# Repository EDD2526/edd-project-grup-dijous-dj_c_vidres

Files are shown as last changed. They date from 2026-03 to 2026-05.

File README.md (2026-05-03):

View this project on [CADLAB.io](https://cadlab.io/project/30197).

# Projecte DJ_C_Vidres (Portes)

> **Autors: Gurpinder Singh Kaur, Adria Pelegri Sabate**  
> **Versió: 5**

---

## Objectiu

PCB per al control d’un sistema de porta i alçavidres d’un vehicle. La placa permet controlar el moviment del vidre i l’actuació de la porta mitjançant botons, gestionar motors amb drivers pont H, detectar finals de carrera i situacions de sobrecorrent, i comunicar-se amb altres sistemes del vehicle mitjançant CAN. També inclou mecanismes de protecció, regulació d’alimentació, programació/debug mitjançant ICSP i test points per facilitar la depuració.

---

## Diagrama de blocs

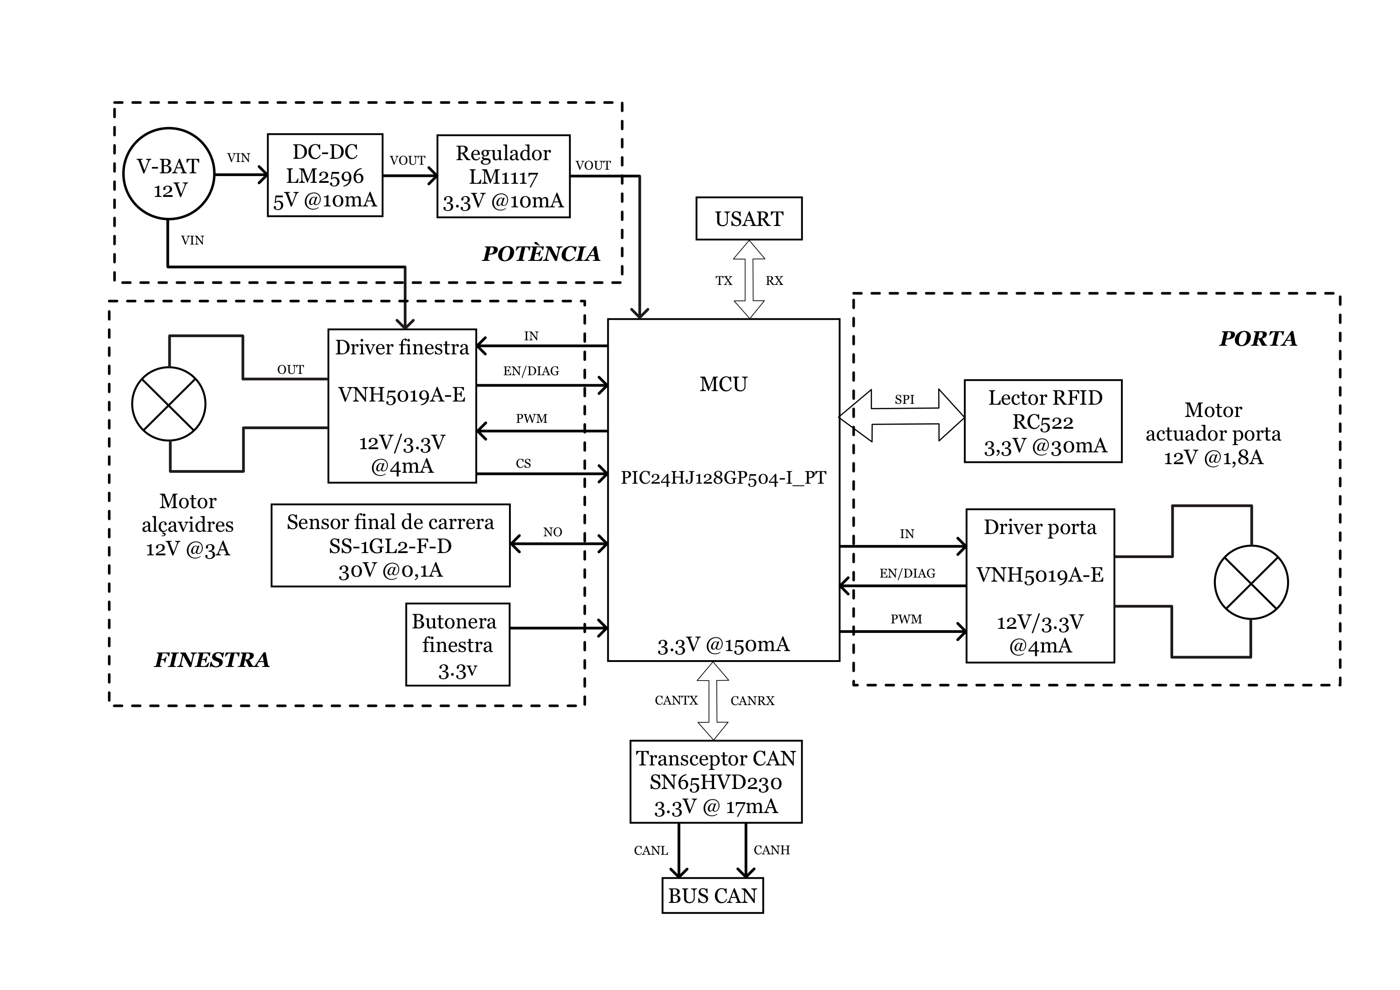
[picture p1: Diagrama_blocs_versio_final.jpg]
Diagrama de blocs


---

## Descripció funcional dels blocs

### Alimentació

La placa s’alimenta a partir d’una entrada de 12 V del vehicle. Aquesta entrada està protegida mitjançant fusible, díode de protecció i TVS. A partir d’aquesta tensió es genera una línia de 5 V mitjançant un convertidor DC-DC LM2596S-5.0. Posteriorment, es genera una línia de 3.3 V mitjançant un regulador LM1117-3.3 per alimentar la lògica digital, el microcontrolador, el transceptor CAN i els perifèrics de baixa tensió.

### Microcontrolador

El sistema està controlat per un microcontrolador **PIC24HJ128GP504-I/PT** alimentat a 3.3 V. Aquest dispositiu gestiona les entrades de botons i sensors, genera les ordres de control dels drivers de motor, llegeix el senyal analògic de corrent, comunica amb el lector RFID i permet la comunicació amb altres sistemes mitjançant CAN.

La placa inclou connector de programació/debug ICSP amb les línies MCLR, PGEC i PGED.

### Drivers de motor

S’utilitzen dos drivers **VNH5019A-E** en configuració de pont H:

- Un driver per al motor  de l’alçavidres;
- Un driver per al motor actuador de la porta.

Cada driver permet controlar el motor en ambdós sentits mitjançant senyals digitals INA, INB i PWM.

### Mesura de corrent i antiatrapament

La mesura de corrent es realitza mitjançant la sortida de current sense del driver VNH5019A-E. Aquest senyal s’envia a una entrada ADC del microcontrolador per detectar situacions de sobrecorrent. Aquesta informació permet implementar una funció  tipus antiatrapament en el motor de l’alçavidres.

### Inputs d’usuari i sensors

La placa incorpora entrades per a:

- Botons de pujada i baixada de l’alçavidres
- Control de bloqueig/desbloqueig de porta
- Sensor de final de carrera

Les entrades digitals es connecten al microcontrolador mitjançant resistències de pull-up/pull-down segons la funcionalitat requerida.

### RFID

El sistema inclou connexió per a un lector RFID RC522. Aquest mòdul permet identificar l’usuari o autoritzar accions del sistema. La comunicació amb el microcontrolador es realitza mitjançant SPI.

### Comunicació CAN

La comunicació amb altres sistemes del vehicle es realitza mitjançant un transceptor **SN65HVD230**. El bus CAN disposa de les línies CANH i CANL.

---

## Requisits / Especificacions

### Alimentació

- Entrada principal: 12 V
- Sortida intermèdia: 5 V
- Alimentació lògica: 3.3 V
- Protecció d’entrada mitjançant fusible, díode i TVS

### Microcontrolador

- Model: PIC24HJ128GP504-I/PT
- Encapsulat: TQFP-44
- Alimentació: 3.3 V
- Programació/debug: ICSP
- Perifèrics utilitzats:
  - PWM per al control dels motors
  - ADC per a la lectura de corrent
  - SPI per al lector RFID
  - CAN per a la comunicació amb el vehicle
  - GPIO per a botons, sensors i diagnòstic

### Motors

- Motor alçavidres:
  - Alimentació: 12 V
  - Corrent màxim estimat: fins a 3 A

- Motor actuador de porta:
  - Alimentació: 12 V
  - Control bidireccional mitjançant pont H
  - Control PWM

### Funcionalitats principals

- Control bidireccional dels motors
- Control de velocitat mitjançant PWM
- Lectura de botons d’usuari
- Lectura de final de carrera
- Detecció de sobrecorrent
- Diagnòstic dels drivers de motor
- Comunicació CAN
- Connexió RFID
- Programació i debug mitjançant ICSP
- Test point per depuració

---

## Components principals

| # | Component | Valor | Quantitat | Footprint | Preu x1 (€) |
|---|---|---|---|---|---|
| 1 | Capacitor | 100nF | 12 | Capacitor_SMD:C_0805_2012Metric | 0,09 |
| 2 | Capacitor | 10uF | 6 | Capacitor_SMD:C_0805_2012Metric | 0,79 |
| 3 | Capacitor | 220uF | 1 | Capacitor_SMD:CP_Elec_8x10 | 0,46 |
| 4 | Capacitor | 22pF | 2 | Capacitor_SMD:C_0805_2012Metric | 0,67 |
| 5 | Capacitor | 100uF | 1 | Capacitor_SMD:CP_Elec_8x10 | 0,69 |
| 6 | Diode Schottky | - | 2 | Diode_SMD:D_SMB_Modified | 0,22 |
| 7 | Diode TVS | - | 1 | Diode_SMD:D_SMB_Modified | 0,66 |
| 8 | Fuse | - | 1 | Fuse:Fuse_1812_4532Metric | 0,45 |
| 9 | Connector | - | 2 | Connector_Dsub:DSUB-9_Pins_Horizontal_P2.77x2.84mm_EdgePinOffset4.9 | 3,89 |
| 10 | Connector | - | 1 | Connector_PinSocket_1.00mm:PinSocket_1x08_P1.00mm_Vertical | 0,80 |
| 11 | Connector | - | 1 | Connector_PinHeader_2.54mm:PinHeader_1x05_P2.54mm_Vertical | 0,24 |
| 12 | Connector | - | 4 | TerminalBlock:TerminalBlock_MaiXu_MX126-5.0-02P_1x02_P5.00mm | 0,09 |
| 13 | Inductor | 33uH | 1 | Inductor_SMD:L_10.4x10.4_H4.8 | 1,38 |
| 14 | Resistor | 120Ω | 1 | Resistor_SMD:R_0805_2012Metric | 1,08 |
| 15 | Resistor | 10kΩ | 10 | Resistor_SMD:R_0805_2012Metric | 1,08 |
| 16 | Resistor | 1kΩ | 1 | Resistor_SMD:R_0805_2012Metric | 1,08 |
| 17 | Switch | - | 1 | Button_Switch_SMD:SW_DPDT_CK_JS202011JCQN | 0,86 |
| 18 | Switch | - | 1 | Button_Switch_THT:SW_CK_JS202011CQN_DPDT_Straight | 0,74 |
| 19 | Switch | - | 1 | Button_Switch_SMD:SW_SPST_TL3342 | 0,50 |
| 20 | Micro | - | 1 | PIC24HJ128GP504-I_PT:QFP80P1200X1200X120-44N | 7,23 |
| 21 | Transceiver | - | 1 | PACKAGE_SO:SOIC-8_3.9x4.9mm_P1.27mm | 1,87 |
| 22 | Motor Drivers | - | 2 | Package_SO:ST_MultiPowerSO-30 | 7,93 |
| 23 | DC-DC | - | 1 | Package_TO_SOT_SMD:TO-263-5_TabPin3 | 5,99 |
| 24 | DC-DC | - | 1 | Package_TO_SOT_SMD:TO-252-3_TabPin2 | 1,12 |
| 25 | Crystal | 8MHz | 1 | Crystal:Crystal_SMD_3225-4Pin_3.2x2.5mm | 0,53 |

## Disseny PCB

La PCB s’ha dissenyat a **dues capes**. S’ha intentat separar funcionalment la zona de potència i la zona lògica per reduir interferències i facilitar el routing.

### Criteris principals de disseny

- Zona de potència situada principalment a l’esquerra de la PCB.
- Microcontrolador situat a la zona central.
- Comunicacions CAN i connectors principals situats a la dreta.
- Inputs i botons situats a la zona inferior/superior.
- Pla de VBAT_PROT per alimentar els drivers de motor.
- Pla de +3.3V per alimentar la part digital.
- Separació entre GND i GNDPWR
- Pistes de potència més amples que les pistes de senyal.
- Test points  per a alimentació, debug, CAN, PWM, diagnòstic i corrent.

### Bus CAN

El transceptor CAN s’ha col·locat pròxim al connector corresponent. Les línies `CANH` i `CANL` s’han mantingut curtes i amb una disposició simètrica.

---

## Test points

S’han afegit test points per facilitar la posada en marxa i la depuració de la placa. Els punts principals són:

- TP_VBAT: alimentació protegida de 12 V
- TP_5V: sortida del convertidor DC-DC
- TP_3V3: alimentació lògica
- TP_GND: massa lògica
- TP_GNDPWR: massa de potència
- TP_MCLR: reset/programació
- TP_PGEC: línia de clock ICSP
- TP_PGED: línia de dades ICSP
- TP_CANH: línia CANH
- TP_CANL: línia CANL
- TP_CURRENT: lectura de corrent
- TP_PWM: control PWM
- TP_WDIAG: diagnòstic del driver de finestra
- TP_DDIAG: diagnòstic del driver de porta

Aquests punts permeten verificar alimentació, comunicació, programació, control dels motors i diagnòstic sense modificar la placa.

---

## Software

### Eines utilitzades

- KiCad 9.0
- LTspice per a simulacions

### Configuració prevista del microcontrolador

- PWM per al control dels drivers de motor
- ADC per a lectura del senyal de corrent
- SPI per al lector RFID
- CAN per a comunicació amb el vehicle
- GPIO per a botons, sensors, finals de carrera i diagnòstic
- ICSP per a programació i debug

### Funcionalitats previstes

#### Control de motors

- Control de pujada i baixada del vidre
- Control d’actuació de la porta
- Control de velocitat mitjançant PWM
- Control de sentit mitjançant INA i INB

#### Seguretat

- Detecció de sobrecorrent
- Funció antiatrapament
- Lectura de final de carrera
- Diagnòstic dels drivers de motor

#### Comunicació

- Comunicació CAN amb altres sistemes del vehicle
- Comunicació SPI amb el lector RFID

#### Debug

- Programació mitjançant ICSP
- Test points per a mesures elèctriques

---

## Verificació

Abans de la fabricació/entrega s’han revisat els punts següents:

- ERC del circuit esquemàtic:
  - 0 errors
  - 6 avisos 
- DRC de la PCB:
  - 0 errors
  - 0 avisos
- Separació entre zona de potència i zona lògica.
- Bus CAN curt i simètric.
- Serigrafia completa i llegible.
- Test points accessibles.

---

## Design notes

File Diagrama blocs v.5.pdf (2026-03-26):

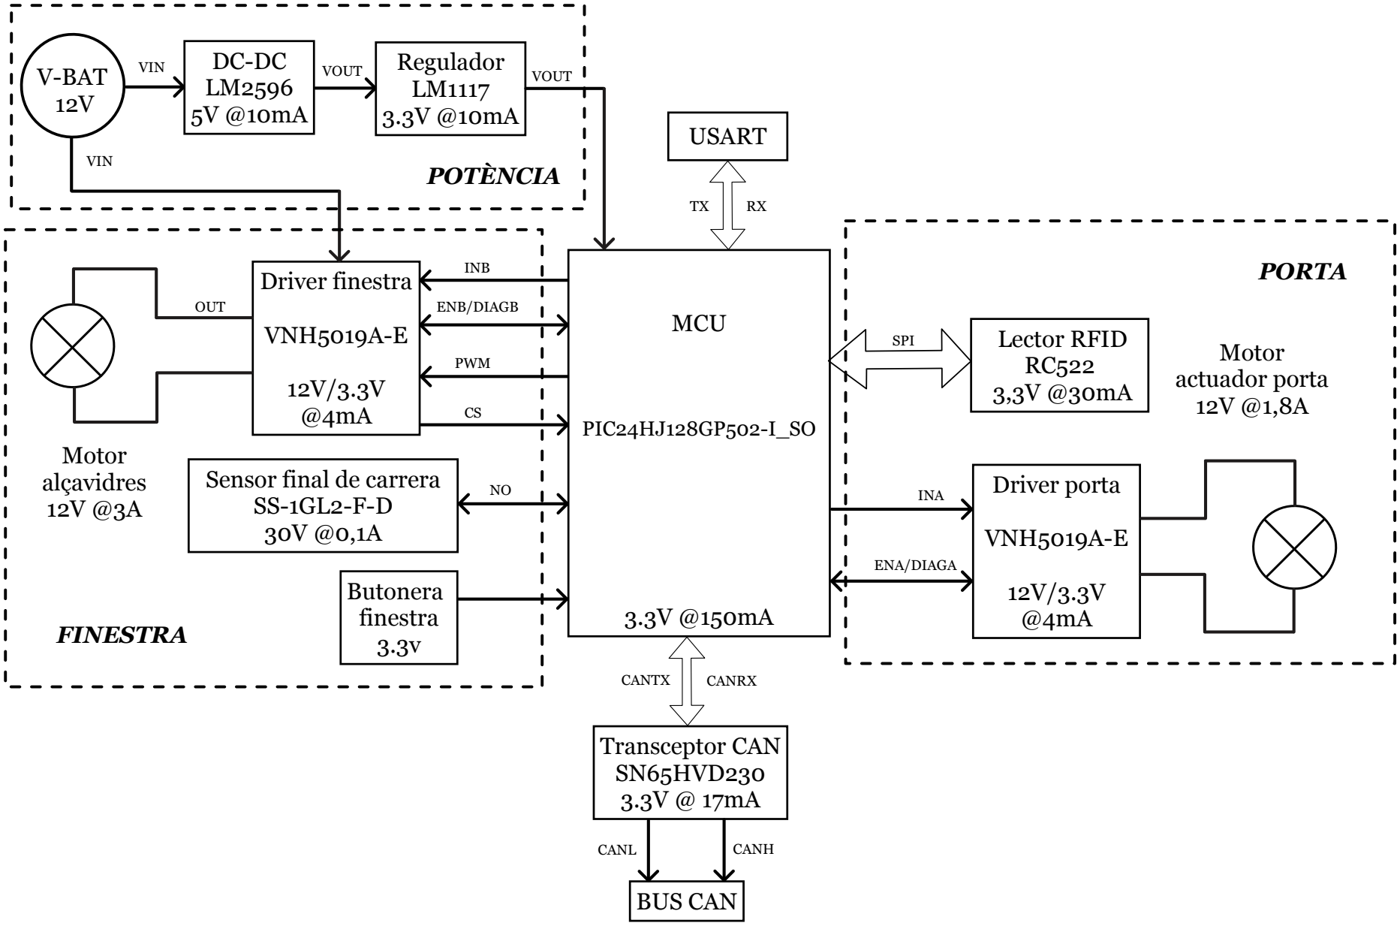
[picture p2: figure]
Regulador LM1117 3.3V @10mA; MCU; PIC24HJ128GP502-I_SO; USART; Lector RFID RC522 3,3V @30mA; Transceptor CAN SN65HVD230 3.3V @ 17mA; CANL; CANH; CANTX; CANRX; Driver finestra; VNH5019A-E; INB; PWM; Motor alçavidres 12V @3A; OUT; Motor actuador porta 12V @1,8A; Butonera finestra 3.3v; Sensor final de carrera SS-1GL2-F-D 30V @0,1A; VIN; VOUT; BUS CAN; V-BAT 12V; FINESTRA; ENB/DIAGB; Driver porta; INA; ENA/DIAGA; PORTA; POTÈNCIA; SPI

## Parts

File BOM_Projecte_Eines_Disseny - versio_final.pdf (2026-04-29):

Component | Descripció | Ref. Fabricant | Package | Datasheet | Proveïdor | Preu | Unitats
PIC24HJ128GP504-I_PT | Microcontrolador | PIC24HJ128GP504-I/PT-ND | | Datasheet (https://ww1.microchip.com/downloads/en/DeviceDoc/70293G.pdf) | DigiKey (https://www.digikey.es/es/products/detail/microchip-technology/PIC24HJ128GP504-I-PT/1635638) | 7,23 € | 1x
LM1117DT-3.3 | Regulador 3.3V | 926-LM1117DTX3.3NOPB | | Datasheet (https://www.ti.com/lit/ds/symlink/lm1117.pdf?ts=1773808432939) | Mouser (https://www.mouser.es/ProductDetail/Texas-Instruments/LM1117DTX-3.3-NOPB?qs=X1J7HmVL2ZFMDtR97FJi7A%3D%3D) | 1,12 € | 1x
LM2596S-5.0 | Regulador 5V | 926-LM2596S-5.0/NOPB | | Datasheet (https://www.ti.com/lit/ds/symlink/lm2596.pdf?ts=1777428369397) | Mouser (https://www.mouser.es/ProductDetail/Texas-Instruments/LM2596S-5.0-NOPB?qs=X1J7HmVL2ZHVjCOmW%252BYINA%3D%3D) | 5,99 € | 1x
VNH5019A-E | H-Bridge (Drivers) | 511-VNH5019A-E | | Datasheet (https://www.st.com/resource/en/datasheet/vnh5019a-e.pdf) | Mouser (https://www.mouser.es/ProductDetail/STMicroelectronics/VNH5019A-E?qs=vV0pr1uq7fB8hoIFkGw2pA%3D%3D) | 7,93 € | 1x
ACI 83094 | Motor alçavidres | | | | AutoZone (https://www.autozone.com/p/aci-window-motor-83094/972601) | 86,99 € | 1x
CINCHING LATCH MOTOR | Motor actuador porta | | | | Johnson Electric (https://shop.johnsonelectric.com/products/cinching-latch-motors) | 30,00 € | 1x
RC522 | Lector RFID | Modulo RFID RC522 | | | ElectroComponentes (https://www.electrocomponentes.es/modulos/825-modulo-rfid-rc522-1356mhz-33v-con-tarjeta-y-llavero.html) | 2,20 € | 1x
SN65HVD230 | Transceptor CAN | 595-SN65HVD230DR | | Datasheet (https://www.ti.com/lit/ds/symlink/sn65hvd232.pdf?ts=1773819356784) | Mouser (https://www.mouser.es/ProductDetail/Texas-Instruments/SN65HVD230DR?qs=QViXGNcIEAtifeQR3pYVUQ%3D%3D) | 1,87 € | 1x
SS-5GLD | Sensor final de carrera | 653-SS-5GLD | | Datasheet (https://www.mouser.es/datasheet/3/39/1/B032-E1.pdf) | Mouser (https://www.mouser.es/ProductDetail/Omron-Electronics/SS-5GLD?qs=0w99tykdtPIPkyQBY6Ojgw%3D%3D) | 2,38 € | 1x

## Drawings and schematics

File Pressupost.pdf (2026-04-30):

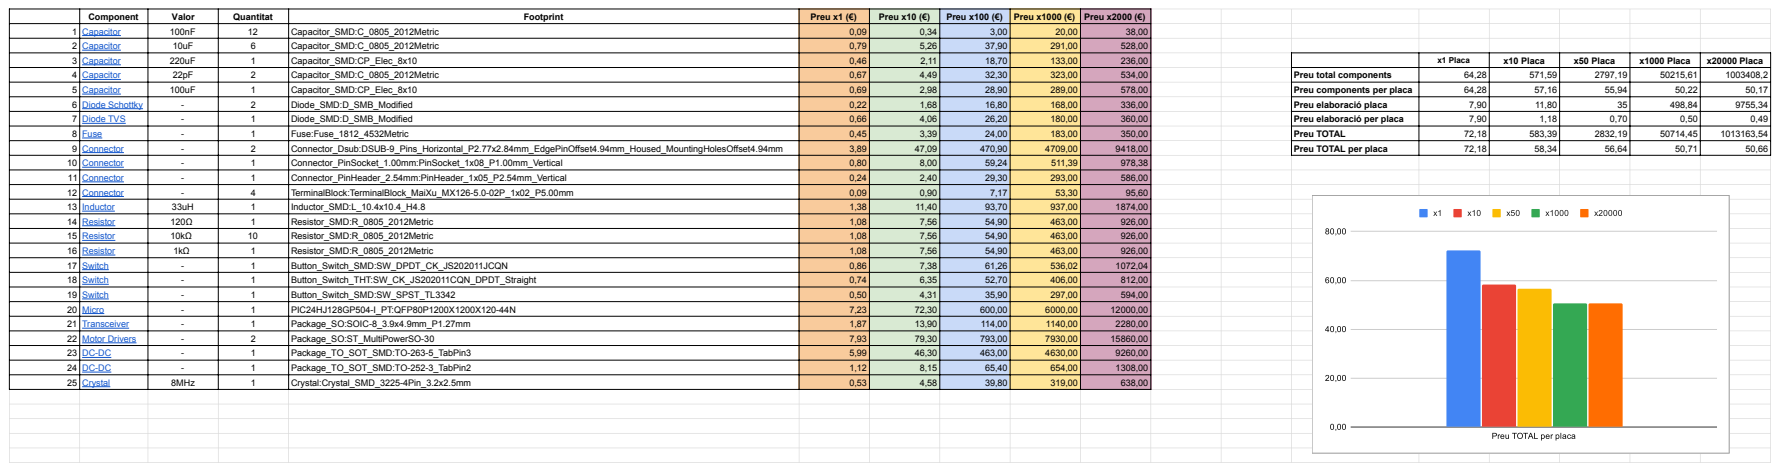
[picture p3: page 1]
Capacitor; Capacitor_SMD:CP_Elec_8x10; x1 Placa; x10 Placa; x50 Placa; x1000 Placa; x20000 Placa; Capacitor_SMD:C_0805_2012Metric; Preu total components; Preu components per placa; Diode Schottky; Diode_SMD:D_SMB_Modified; Preu elaboració placa; Diode TVS; Preu elaboració per placa; Fuse; Fuse:Fuse_1812_4532Metric; Preu TOTAL; Connector; Connector_Dsub:DSUB-9_Pins_Horizontal_P2.77x2.84mm_EdgePinOffset4.94mm_Housed_MountingHolesOffset4.94mm; Preu TOTAL per placa

Component | Valor | Quantitat | Footprint | Preu x1 (€) | Preu x10 (€) | Preu x100 (€) | Preu x1000 (€) | Preu x2000 (€)
1 | Capacitor (https://www.mouser.es/ProductDetail/SEI-Stackpole/CML0805X7R104KT50V?qs=IKkN%2F947nfA6xYvTrzMxEg%3D%3D) | 100nF | 12 | Capacitor_SMD:C_0805_2012Metric | 0,09 | 0,34 | 3,00 | 20,00 | 38,00
2 | Capacitor (https://www.mouser.es/ProductDetail/KYOCERA-AVX/0805X7R106KT1AT?qs=XAiT9M5g4x%252Bo4s7i6ql7Og%3D%3D) | 10uF | 6 | Capacitor_SMD:C_0805_2012Metric | 0,79 | 5,26 | 37,90 | 291,00 | 528,00

10 | Connector (https://www.digikey.com/en/products/detail/gct/BC065-08-A-L-D/12549935) | - | 1 | Connector_PinSocket_1.00mm:PinSocket_1x08_P1.00mm_Vertical | 0,80 | 8,00 | 59,24 | 511,39 | 978,38
11 | Connector (https://uk.rs-online.com/web/p/pcb-headers/2518121) | - | 1 | Connector_PinHeader_2.54mm:PinHeader_1x05_P2.54mm_Vertical | 0,24 | 2,40 | 29,30 | 293,00 | 586,00
12 | Connector (https://jlcpcb.com/partdetail/MAX-MX126R_5_0_02P_GN01_Cu_SA/C5188436) | - | 4 | TerminalBlock:TerminalBlock_MaiXu_MX126-5.0-02P_1x02_P5.00mm | 0,09 | 0,90 | 7,17 | 53,30 | 95,60
13 | Inductor (https://www.mouser.es/ProductDetail/TDK/B82464P4333M000?qs=4t%252Bzdmp%252BdtgGvdkS4aj5uA%3D%3D) | 33uH | 1 | Inductor_SMD:L_10.4x10.4_H4.8 | 1,38 | 11,40 | 93,70 | 937,00 | 1874,00
14 | Resistor (https://www.mouser.es/ProductDetail/SEI-Stackpole/RNAN0805BKE120R) | 120Ω | 1 | Resistor_SMD:R_0805_2012Metric | 1,08 | 7,56 | 54,90 | 463,00 | 926,00
15 | Resistor (https://www.mouser.es/ProductDetail/SEI-Stackpole/RNAN0805BKE10K0) | 10kΩ | 10 | Resistor_SMD:R_0805_2012Metric | 1,08 | 7,56 | 54,90 | 463,00 | 926,00
16 | Resistor (https://www.mouser.es/ProductDetail/SEI-Stackpole/RNAN0805BKE10K0) | 1kΩ | 1 | Resistor_SMD:R_0805_2012Metric | 1,08 | 7,56 | 54,90 | 463,00 | 926,00
17 | Switch (https://www.digikey.es/es/products/detail/c-k/JS202011JCQN/6137630) | - | 1 | Button_Switch_SMD:SW_DPDT_CK_JS202011JCQN | 0,86 | 7,38 | 61,26 | 536,02 | 1072,04
18 | Switch (https://www.mouser.es/ProductDetail/CK/JS202011CQN?qs=LgMIjt8LuD%2Fe%252BE3iTcEFYw%3D%3D) | - | 1 | Button_Switch_THT:SW_CK_JS202011CQN_DPDT_Straight | 0,74 | 6,35 | 52,70 | 406,00 | 812,00
19 | Switch (https://www.mouser.es/ProductDetail/E-Switch/TL3342F260QG?qs=6C6BR4UgC3Of90YOH%2FEXyw%3D%3D) | - | 1 | Button_Switch_SMD:SW_SPST_TL3342 | 0,50 | 4,31 | 35,90 | 297,00 | 594,00
20 | Micro (https://www.digikey.es/es/products/detail/microchip-technology/PIC24HJ128GP504-I-PT/1635638) | - | 1 | PIC24HJ128GP504-I_PT:QFP80P1200X1200X120-44N | 7,23 | 72,30 | 600,00 | 6000,00 | 12000,00
21 | Transceiver (https://www.mouser.es/ProductDetail/Texas-Instruments/SN65HVD230DR?qs=QViXGNcIEAtifeQR3pYVUQ%3D%3D) | - | 1 | Package_SO:SOIC-8_3.9x4.9mm_P1.27mm | 1,87 | 13,90 | 114,00 | 1140,00 | 2280,00
22 | Motor Drivers (https://www.mouser.es/ProductDetail/STMicroelectronics/VNH5019A-E?qs=vV0pr1uq7fB8hoIFkGw2pA%3D%3D) | - | 2 | Package_SO:ST_MultiPowerSO-30 | 7,93 | 79,30 | 793,00 | 7930,00 | 15860,00
23 | DC-DC (https://www.mouser.es/ProductDetail/Texas-Instruments/LM2596S-5.0-NOPB?qs=X1J7HmVL2ZHVjCOmW%252BYINA%3D%3D) | - | 1 | Package_TO_SOT_SMD:TO-263-5_TabPin3 | 5,99 | 46,30 | 463,00 | 4630,00 | 9260,00
24 | DC-DC (https://www.mouser.es/ProductDetail/Texas-Instruments/LM1117DTX-3.3-NOPB?qs=X1J7HmVL2ZFMDtR97FJi7A%3D%3D) | - | 1 | Package_TO_SOT_SMD:TO-252-3_TabPin2 | 1,12 | 8,15 | 65,40 | 654,00 | 1308,00
25 | Crystal (https://www.mouser.es/ProductDetail/ECS/ECS-80-12-33-JGN-TR3?qs=e8oIoAS2J1SbcfL8r4NkgA%3D%3D) | 8MHz | 1 | Crystal:Crystal_SMD_3225-4Pin_3.2x2.5mm | 0,53 | 4,58 | 39,80 | 319,00 | 638,00

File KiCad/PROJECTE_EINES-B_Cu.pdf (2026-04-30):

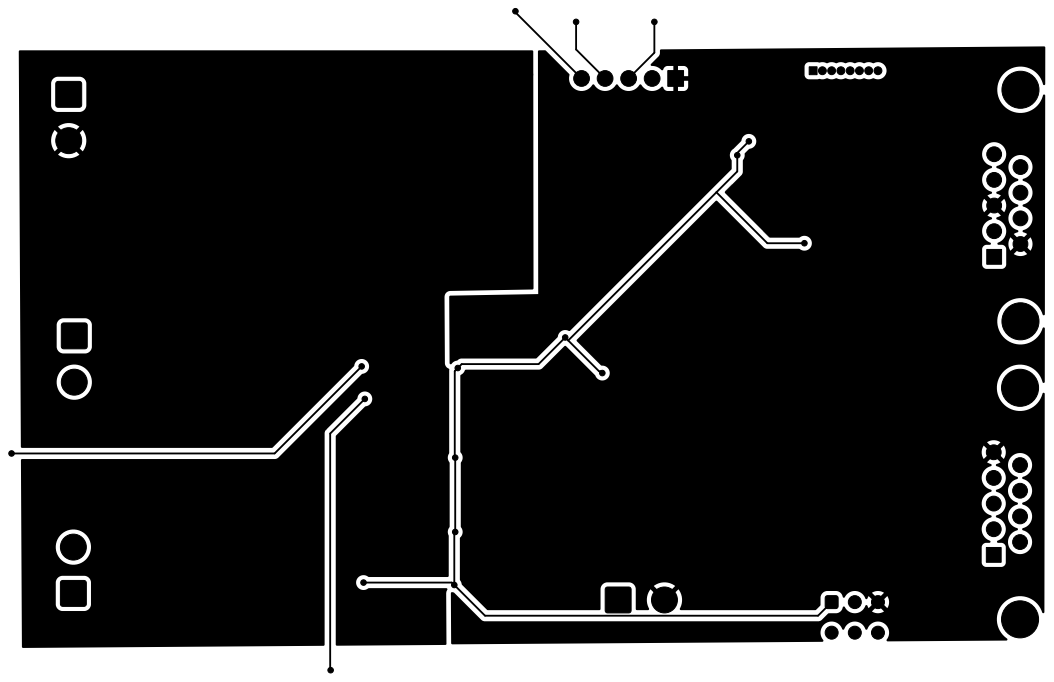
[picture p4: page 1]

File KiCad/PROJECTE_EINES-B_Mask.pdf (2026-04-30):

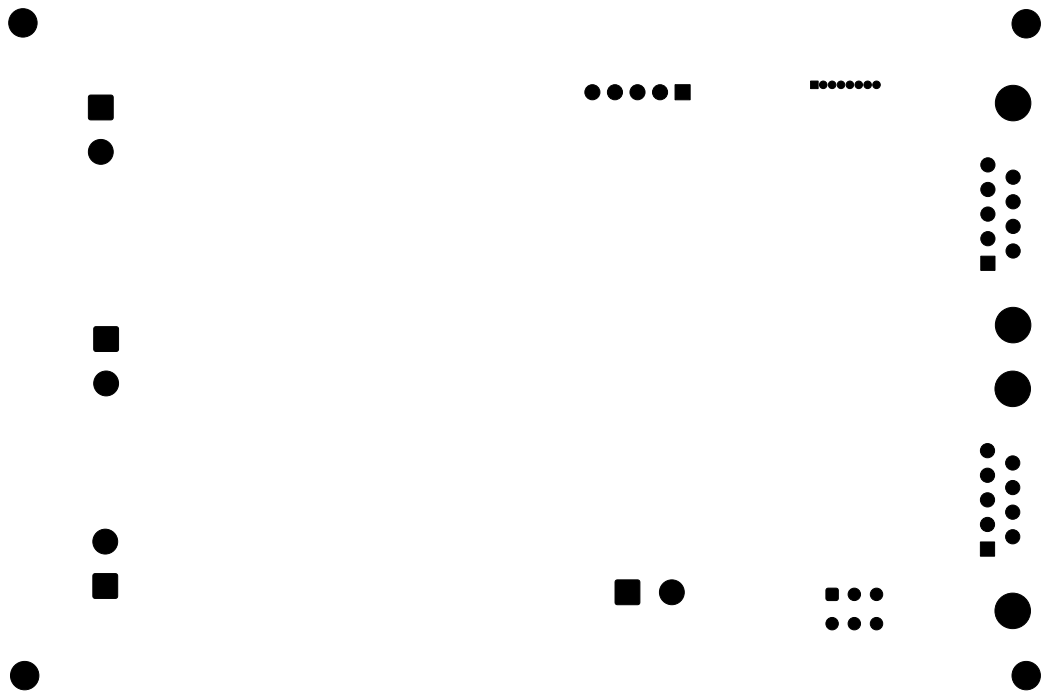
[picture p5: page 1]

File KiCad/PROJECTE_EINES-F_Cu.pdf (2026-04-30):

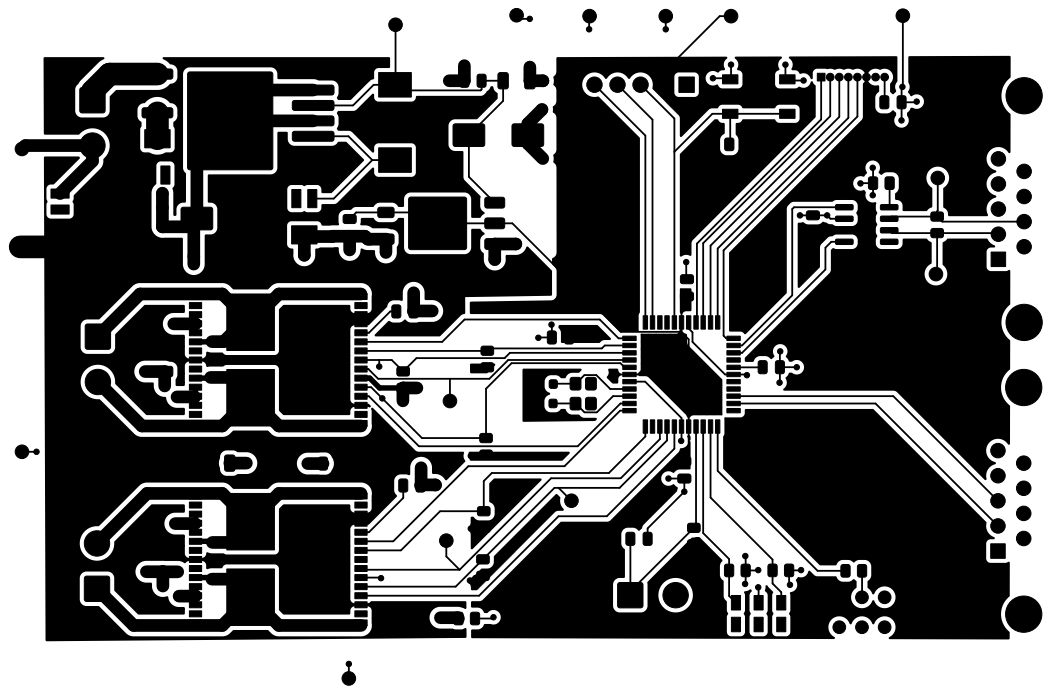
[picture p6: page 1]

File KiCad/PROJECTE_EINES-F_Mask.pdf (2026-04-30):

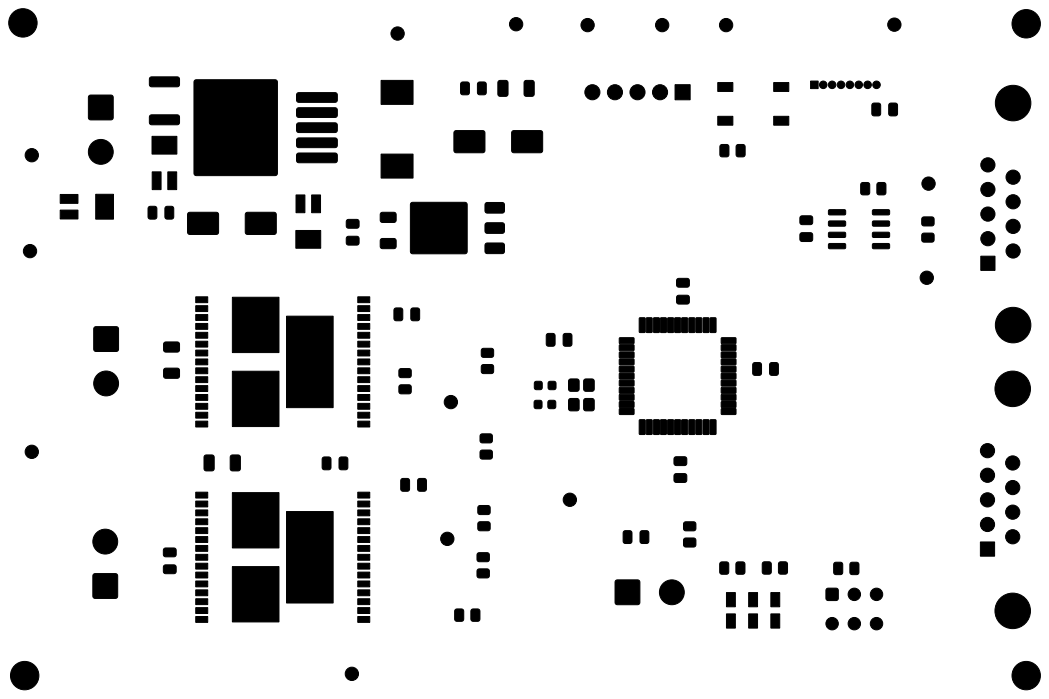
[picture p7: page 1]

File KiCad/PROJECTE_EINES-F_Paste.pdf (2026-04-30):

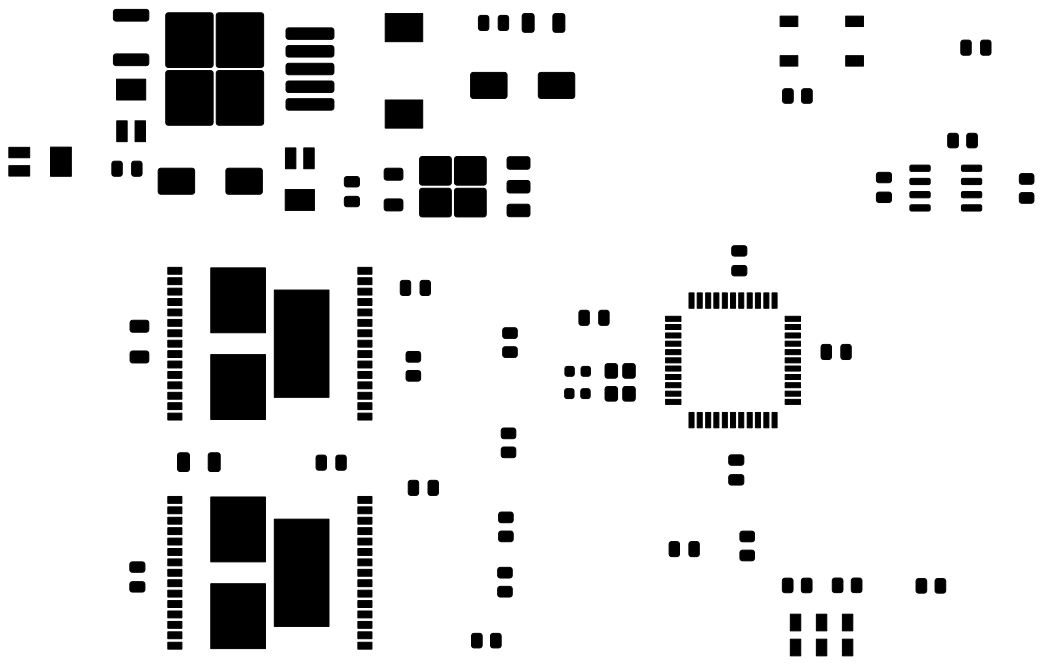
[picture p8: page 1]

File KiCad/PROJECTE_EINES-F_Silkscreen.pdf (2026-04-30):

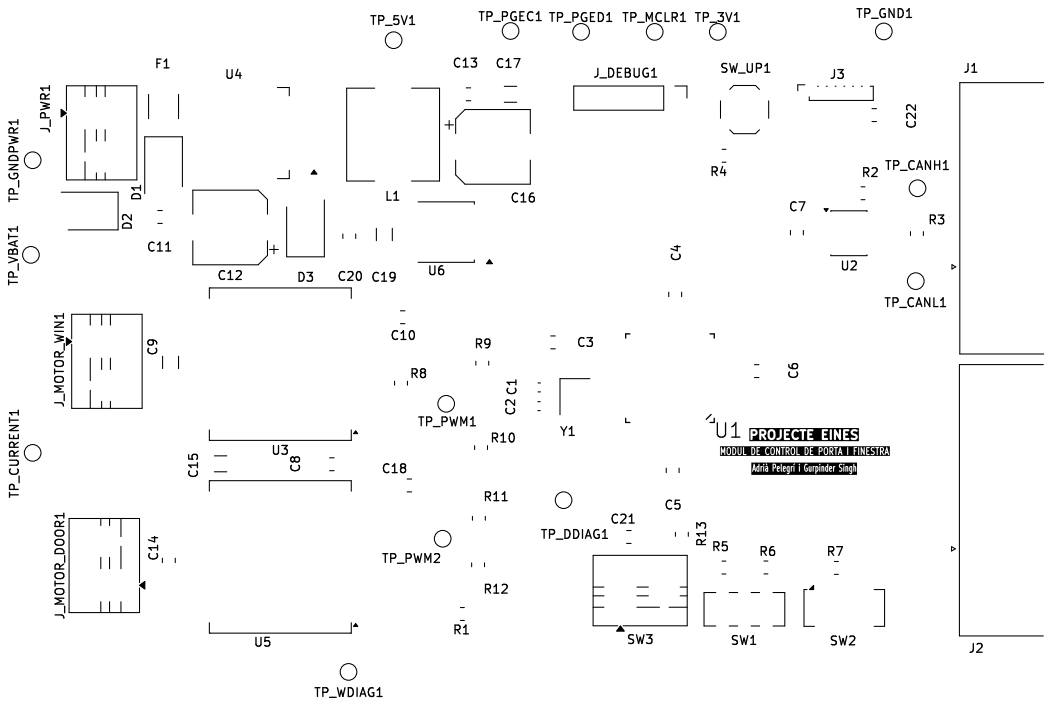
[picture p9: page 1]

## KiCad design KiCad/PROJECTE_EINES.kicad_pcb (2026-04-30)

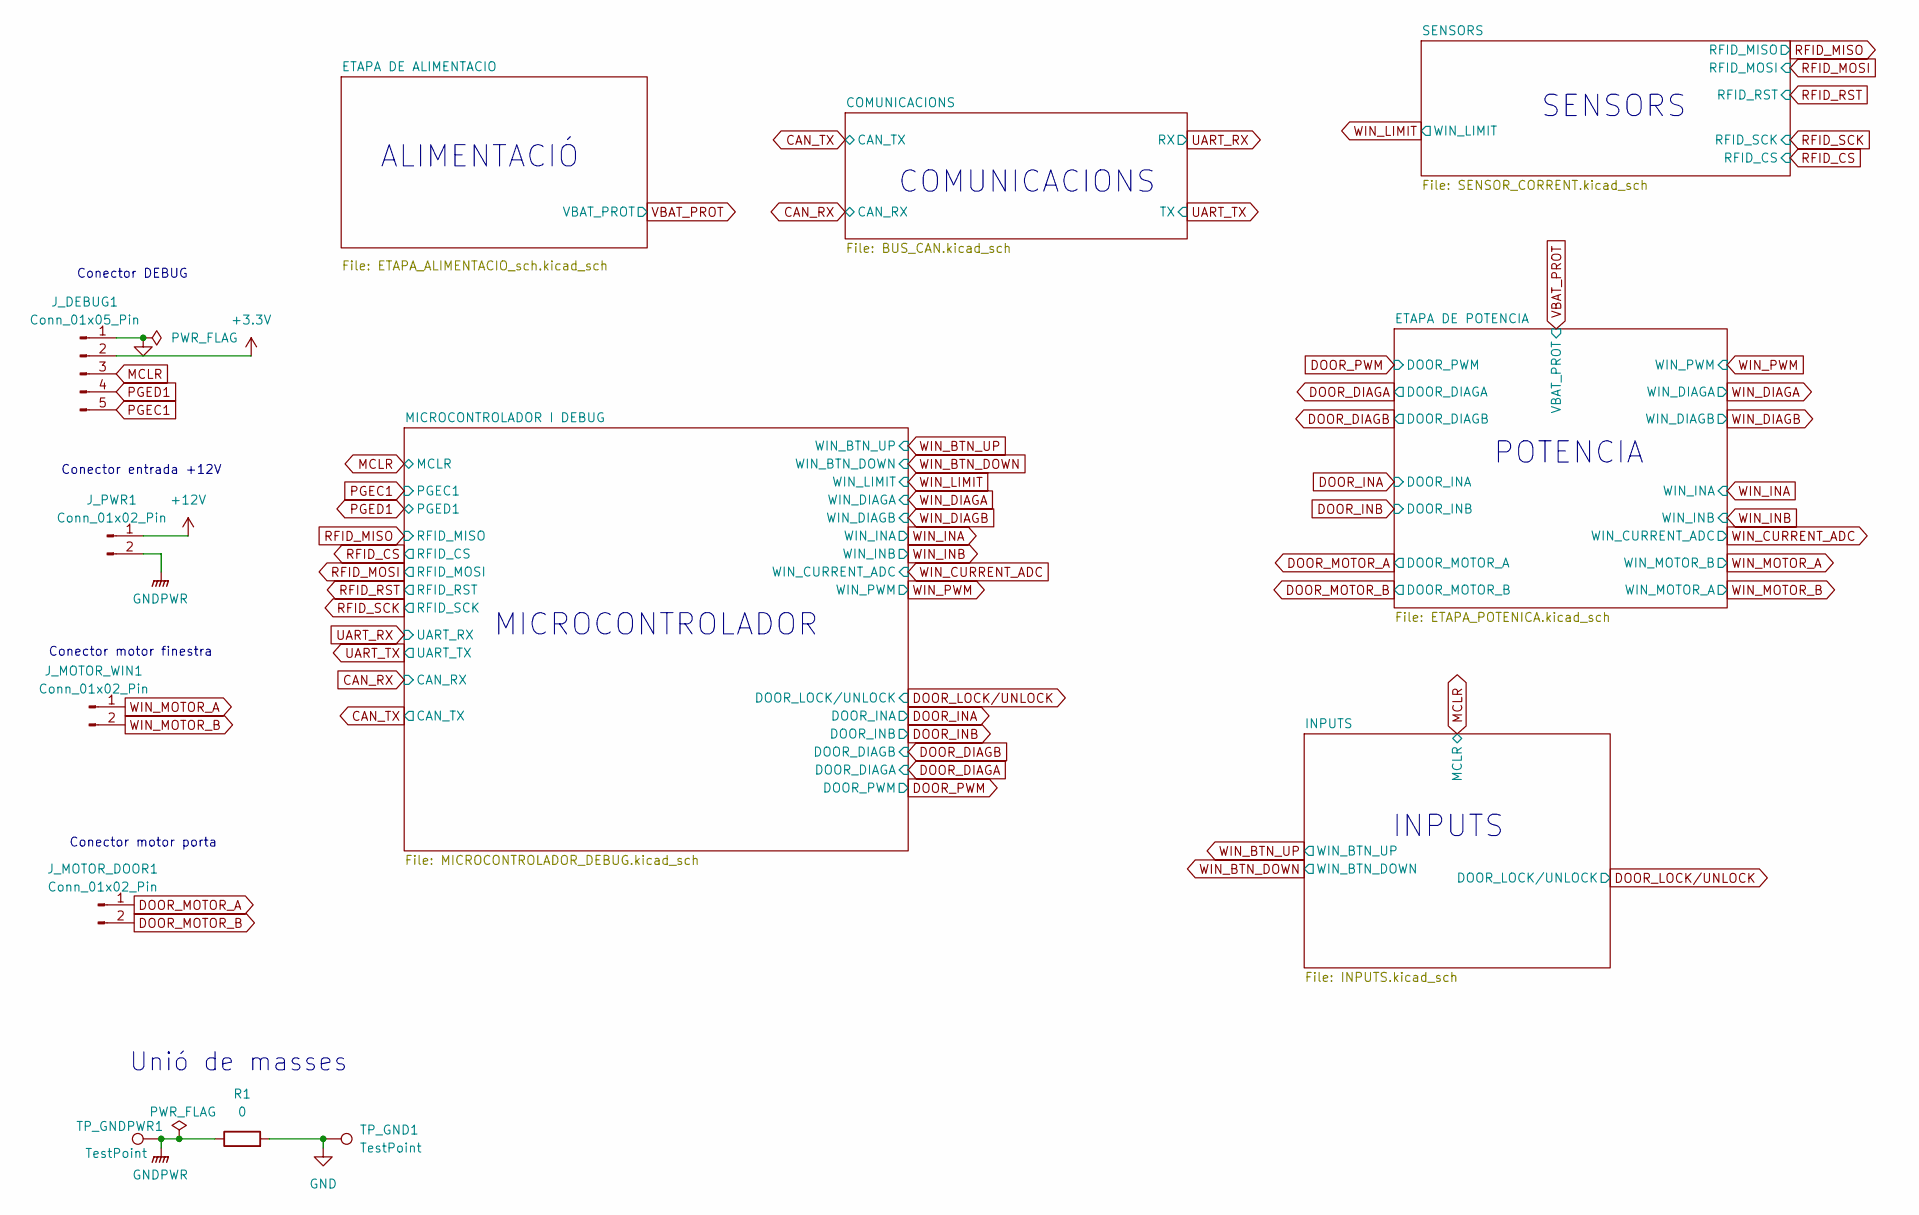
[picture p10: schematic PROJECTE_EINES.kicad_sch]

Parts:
J_DEBUG1: Conn_01x05_Pin; PinHeader_1x05_P2.54mm_Vertical
J_MOTOR_DOOR1: Conn_01x02_Pin; TerminalBlock_MaiXu_MX126-5.0-02P_1x02_P5.00mm
J_MOTOR_WIN1: Conn_01x02_Pin; TerminalBlock_MaiXu_MX126-5.0-02P_1x02_P5.00mm
J_PWR1: Conn_01x02_Pin; TerminalBlock_MaiXu_MX126-5.0-02P_1x02_P5.00mm
R1: 0; R_0805_2012Metric
TP_GND1: TestPoint; TestPoint_Pad_D1.5mm
TP_GNDPWR1: TestPoint; TestPoint_Pad_D1.5mm

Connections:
+3.3V: J_DEBUG1.2; also elsewhere on the board
+12V: J_PWR1.1; also elsewhere on the board
DOOR_MOTOR_A: J_MOTOR_DOOR1.1; also elsewhere on the board
DOOR_MOTOR_B: J_MOTOR_DOOR1.2; also elsewhere on the board
GND: J_DEBUG1.1, R1.2, TP_GND1.1; also elsewhere on the board
GNDPWR: J_PWR1.2, R1.1, TP_GNDPWR1.1; also elsewhere on the board
MCLR: J_DEBUG1.3; also elsewhere on the board
PGEC1: J_DEBUG1.5; also elsewhere on the board
PGED1: J_DEBUG1.4; also elsewhere on the board
WIN_MOTOR_A: J_MOTOR_WIN1.1; also elsewhere on the board
WIN_MOTOR_B: J_MOTOR_WIN1.2; also elsewhere on the board

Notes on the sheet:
Unió de masses
COMUNICACIONS
POTENCIA
Conector motor finestra
Conector DEBUG
MICROCONTROLADOR
INPUTS
Conector motor porta
ALIMENTACIÓ
Conector entrada +12V
SENSORS

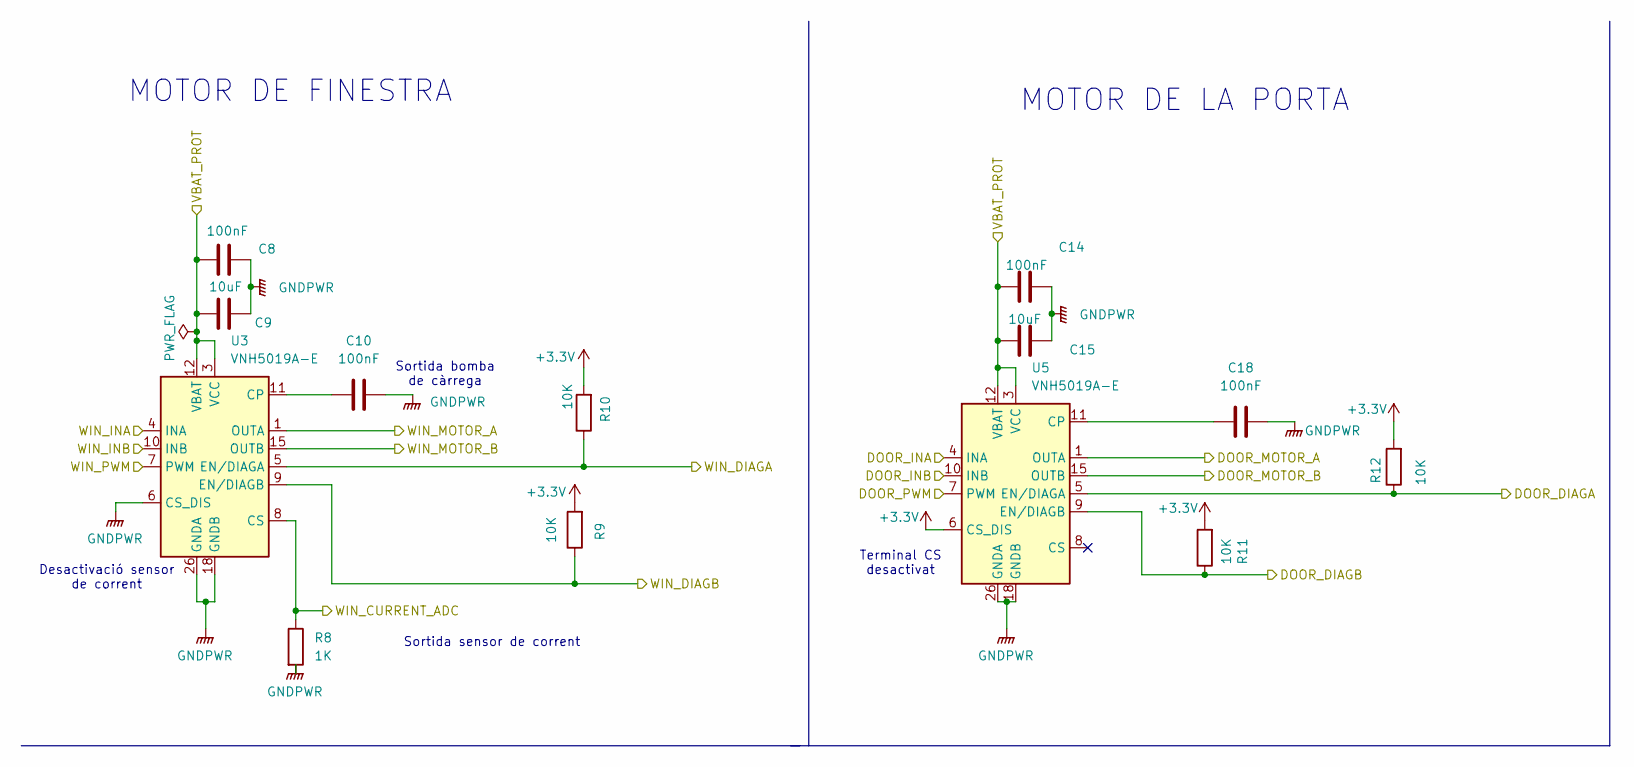
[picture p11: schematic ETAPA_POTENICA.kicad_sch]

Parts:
C8, C10, C14, C18: 100nF; C_0805_2012Metric
C9, C15: 10uF; C_1206_3216Metric
R8: 1K; R_0805_2012Metric
R9, R10, R11, R12: 10K; R_0805_2012Metric
U3, U5: VNH5019A-E; ST_MultiPowerSO-30

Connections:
+3.3V: R9.2, R10.2, R11.2, R12.2, U5.6 (CS_DIS); also elsewhere on the board
DOOR_DIAGA: R12.1, U5.5 (EN/DIAGA); also elsewhere on the board
DOOR_DIAGB: R11.1, U5.9 (EN/DIAGB); also elsewhere on the board
DOOR_INA: U5.4 (INA); also elsewhere on the board
DOOR_INB: U5.10 (INB); also elsewhere on the board
DOOR_MOTOR_A: U5.1 (OUTA), U5.25 (OUTA), U5.30 (OUTA), U5.33 (OUTA); also elsewhere on the board
DOOR_MOTOR_B: U5.15 (OUTB), U5.16 (OUTB), U5.21 (OUTB), U5.32 (OUTB); also elsewhere on the board
DOOR_PWM: U5.7 (PWM); also elsewhere on the board
GNDPWR: C8.2, C9.2, C10.1, C14.2, C15.2, C18.1, R8.2, U3.6 (CS_DIS), U3.18 (GNDB), U3.19 (GNDB), U3.20 (GNDB), U3.26 (GNDA), U3.27 (GNDA), U3.28 (GNDA), U5.18 (GNDB), U5.19 (GNDB), U5.20 (GNDB), U5.26 (GNDA), U5.27 (GNDA), U5.28 (GNDA); also elsewhere on the board
unnamed: C10.2, U3.11 (CP)
unnamed: C18.2, U5.11 (CP)
VBAT_PROT: C8.1, C9.1, C14.1, C15.1, U3.3 (VCC), U3.12 (VBAT), U3.13 (VCC), U3.23 (VCC), U3.31 (VCC), U5.3 (VCC), U5.12 (VBAT), U5.13 (VCC), U5.23 (VCC), U5.31 (VCC); also elsewhere on the board
WIN_CURRENT_ADC: R8.1, U3.8 (CS); also elsewhere on the board
WIN_DIAGA: R10.1, U3.5 (EN/DIAGA); also elsewhere on the board
WIN_DIAGB: R9.1, U3.9 (EN/DIAGB); also elsewhere on the board
WIN_INA: U3.4 (INA); also elsewhere on the board
WIN_INB: U3.10 (INB); also elsewhere on the board
WIN_MOTOR_A: U3.15 (OUTB), U3.16 (OUTB), U3.21 (OUTB), U3.32 (OUTB); also elsewhere on the board
WIN_MOTOR_B: U3.1 (OUTA), U3.25 (OUTA), U3.30 (OUTA), U3.33 (OUTA); also elsewhere on the board
WIN_PWM: U3.7 (PWM); also elsewhere on the board

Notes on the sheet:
Sortida bomba de càrrega
MOTOR DE FINESTRA
MOTOR DE LA PORTA
Desactivació sensor de corrent
Terminal CS desactivat
Sortida sensor de corrent

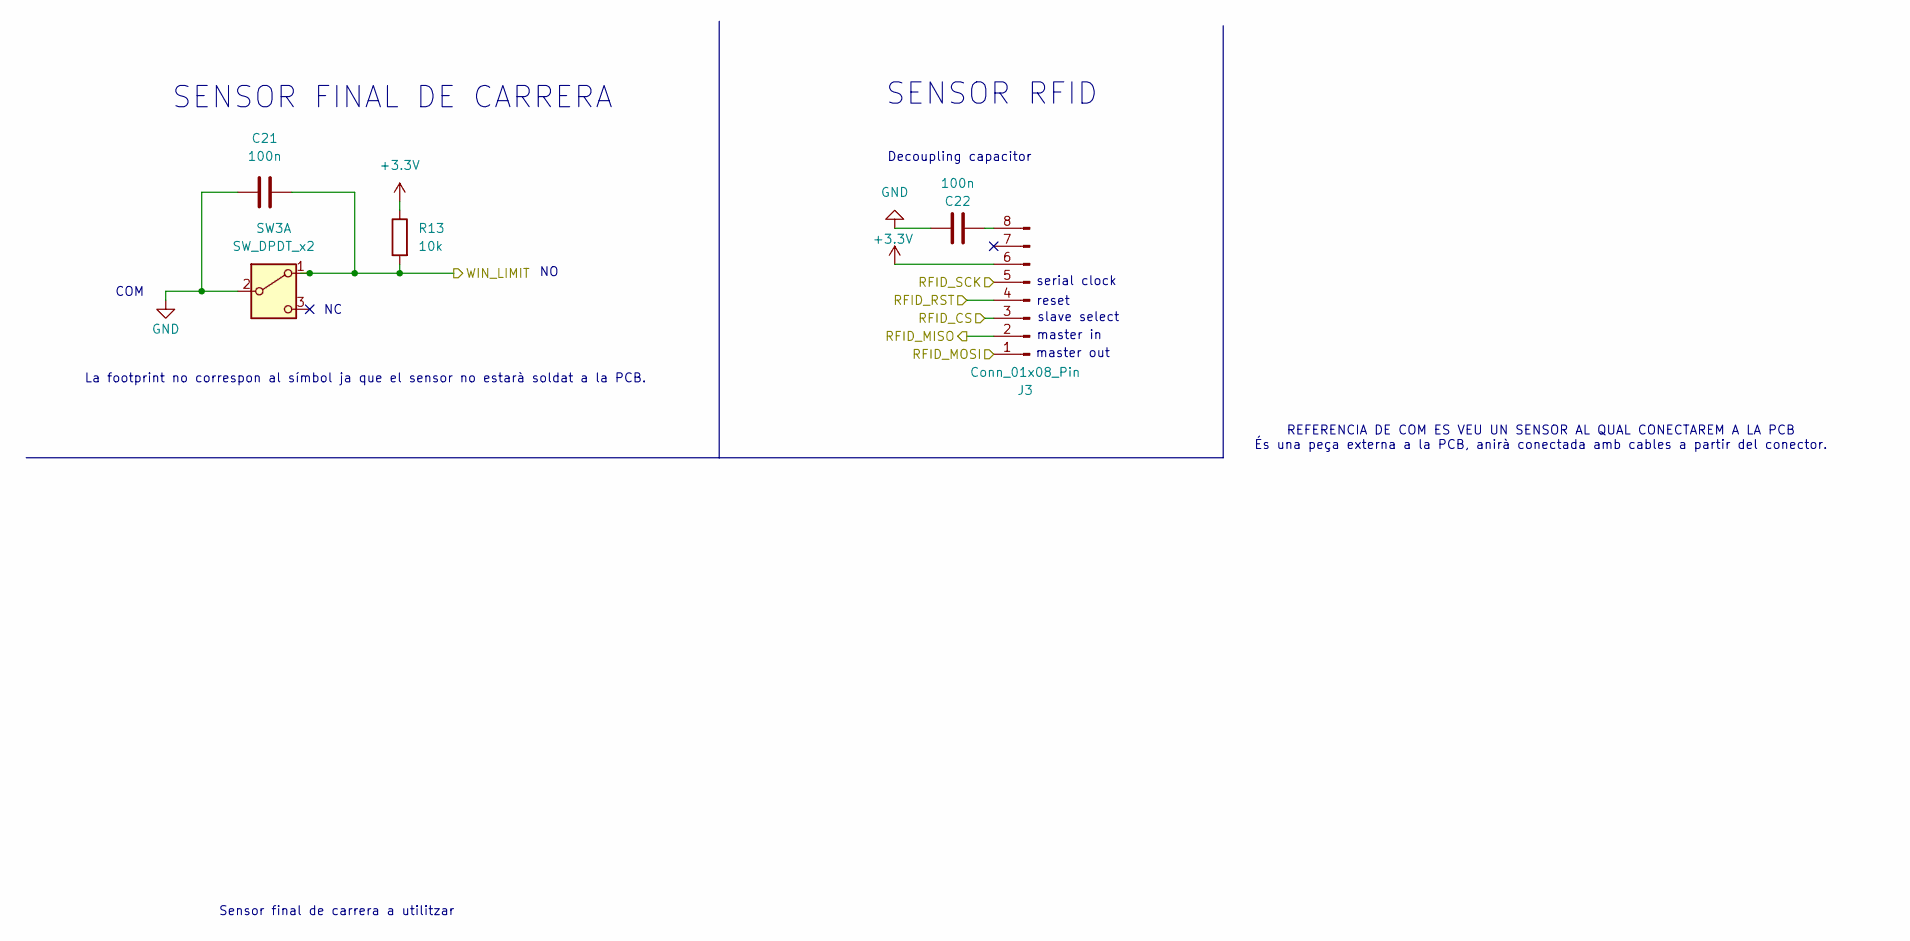
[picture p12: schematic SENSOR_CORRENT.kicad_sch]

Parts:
C21, C22: 100n; C_0805_2012Metric
J3: Conn_01x08_Pin; PinSocket_1x08_P1.00mm_Vertical
R13: 10k; R_0805_2012Metric
SW3: SW_DPDT_x2; TerminalBlock_MaiXu_MX126-5.0-02P_1x02_P5.00mm

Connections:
+3.3V: J3.6 (GND), R13.1; also elsewhere on the board
GND: C21.1, C22.2, SW3.2 (B); also elsewhere on the board
unnamed: C22.1, J3.8 (3.3V)
RFID_CS: J3.3 (MOSI); also elsewhere on the board
RFID_MISO: J3.2 (SCK); also elsewhere on the board
RFID_MOSI: J3.1 (SDA); also elsewhere on the board
RFID_RST: J3.4 (MISO); also elsewhere on the board
RFID_SCK: J3.5 (IRQ); also elsewhere on the board
WIN_LIMIT: C21.2, R13.2, SW3.1 (A); also elsewhere on the board

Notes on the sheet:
La footprint no correspon al símbol ja que el sensor no estarà soldat a la PCB.
Decoupling capacitor
serial clock
COM
slave select
SENSOR RFID
REFERENCIA DE COM ES VEU UN SENSOR AL QUAL CONECTAREM A LA PCB És una peça externa a la PCB, anirà conectada amb cables a partir del conector.
Sensor final de carrera a utilitzar
master in
reset
SENSOR FINAL DE CARRERA
master out

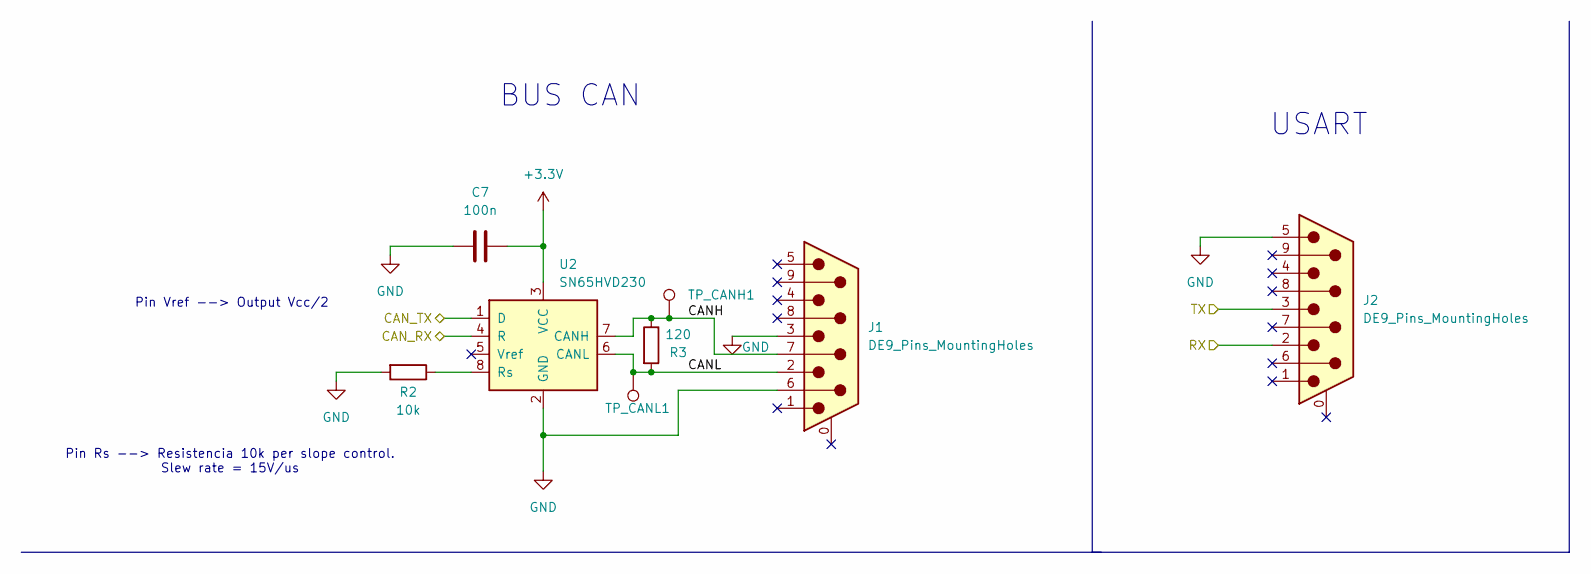
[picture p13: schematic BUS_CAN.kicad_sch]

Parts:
C7: 100n; C_0805_2012Metric
J1, J2: DE9_Pins_MountingHoles; DSUB-9_Pins_Horizontal_P2.77x2.84mm_EdgePinOffset4.94mm_Hou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
R2: 10k; R_0805_2012Metric
R3: 120; R_0805_2012Metric
TP_CANH1: TestPoint_Pad_D1.5mm
TP_CANL1: TestPoint_Pad_D1.5mm
U2: SN65HVD230; SOIC-8_3.9x4.9mm_P1.27mm

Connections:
+3.3V: C7.2, U2.3 (VCC); also elsewhere on the board
/COMUNICACIONS/CANH: J1.7, R3.1, TP_CANH1.1, U2.7 (CANH)
/COMUNICACIONS/CANL: J1.2, R3.2, TP_CANL1.1, U2.6 (CANL)
CAN_RX: U2.4 (R); also elsewhere on the board
CAN_TX: U2.1 (D); also elsewhere on the board
GND: C7.1, J1.3, J1.6, J2.5, R2.2, U2.2 (GND); also elsewhere on the board
unnamed: R2.1, U2.8 (Rs)
UART_RX: J2.2; also elsewhere on the board
UART_TX: J2.3; also elsewhere on the board

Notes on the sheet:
USART
Pin Vref --> Output Vcc/2
Pin Rs --> Resistencia 10k per slope control. Slew rate = 15V/us
BUS CAN

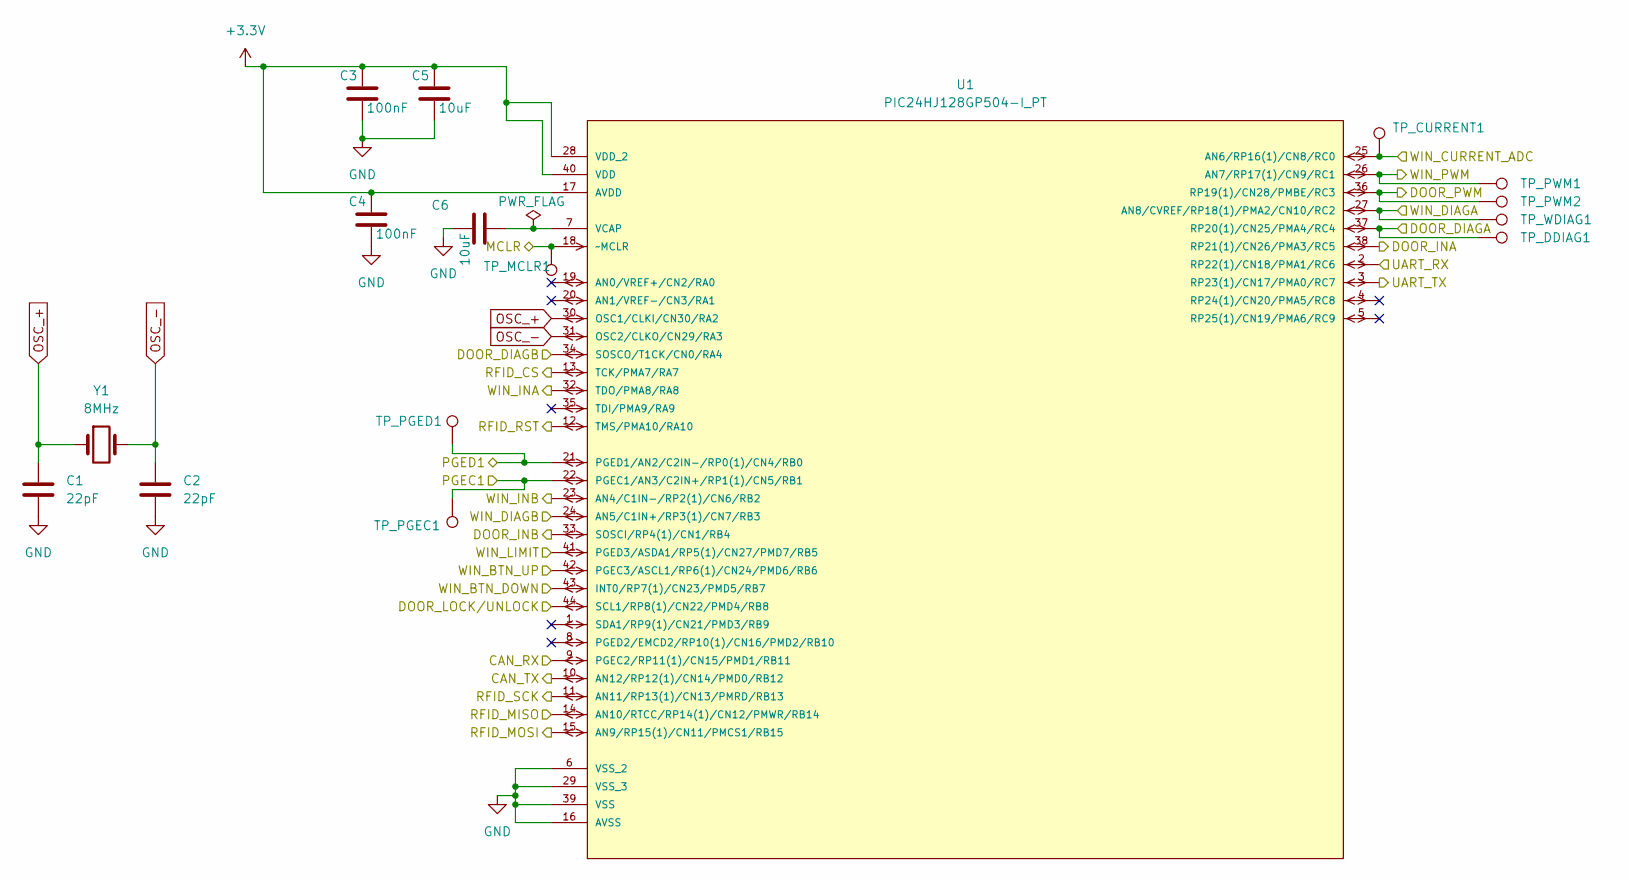
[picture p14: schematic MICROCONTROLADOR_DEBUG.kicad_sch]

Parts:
C1, C2: 22pF; C_0603_1608Metric
C3, C4: 100nF; C_0805_2012Metric
C5, C6: 10uF; C_0805_2012Metric
TP_CURRENT1: TestPoint_Pad_D1.5mm
TP_DDIAG1: TestPoint_Pad_D1.5mm
TP_MCLR1: TestPoint_Pad_D1.5mm
TP_PGEC1: TestPoint_Pad_D1.5mm
TP_PGED1: TestPoint_Pad_D1.5mm
TP_PWM1, TP_PWM2: TestPoint_Pad_D1.5mm
TP_WDIAG1: TestPoint_Pad_D1.5mm
U1: PIC24HJ128GP504-I_PT; QFP80P1200X1200X120-44N; MPN PIC24HJ128GP504-I/PT
Y1: 8MHz; Crystal_SMD_3225-4Pin_3.2x2.5mm

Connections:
+3.3V: C3.1, C4.1, C5.1, U1.17 (AVDD), U1.28 (VDD_2), U1.40 (VDD); also elsewhere on the board
CAN_RX: U1.9 (PGEC2/RP11(1)/CN15/PMD1/RB11); also elsewhere on the board
CAN_TX: U1.10 (AN12/RP12(1)/CN14/PMD0/RB12); also elsewhere on the board
DOOR_DIAGA: TP_DDIAG1.1, U1.37 (RP20(1)/CN25/PMA4/RC4); also elsewhere on the board
DOOR_DIAGB: U1.34 (SOSCO/T1CK/CN0/RA4); also elsewhere on the board
DOOR_INA: U1.38 (RP21(1)/CN26/PMA3/RC5); also elsewhere on the board
DOOR_INB: U1.33 (SOSCI/RP4(1)/CN1/RB4); also elsewhere on the board
DOOR_LOCK/UNLOCK: U1.44 (SCL1/RP8(1)/CN22/PMD4/RB8); also elsewhere on the board
DOOR_PWM: TP_PWM2.1, U1.36 (RP19(1)/CN28/PMBE/RC3); also elsewhere on the board
GND: C1.2, C2.2, C3.2, C4.2, C5.2, C6.2, U1.6 (VSS_2), U1.16 (AVSS), U1.29 (VSS_3), U1.39 (VSS); also elsewhere on the board
MCLR: TP_MCLR1.1, U1.18 (~MCLR); also elsewhere on the board
unnamed: C6.1, U1.7 (VCAP)
OSC_+: C1.1, U1.30 (OSC1/CLKI/CN30/RA2), Y1.1
OSC_-: C2.1, U1.31 (OSC2/CLKO/CN29/RA3), Y1.2
PGEC1: TP_PGEC1.1, U1.22 (PGEC1/AN3/C2IN+/RP1(1)/CN5/RB1); also elsewhere on the board
PGED1: TP_PGED1.1, U1.21 (PGED1/AN2/C2IN-/RP0(1)/CN4/RB0); also elsewhere on the board
RFID_CS: U1.13 (TCK/PMA7/RA7); also elsewhere on the board
RFID_MISO: U1.14 (AN10/RTCC/RP14(1)/CN12/PMWR/RB14); also elsewhere on the board
RFID_MOSI: U1.15 (AN9/RP15(1)/CN11/PMCS1/RB15); also elsewhere on the board
RFID_RST: U1.12 (TMS/PMA10/RA10); also elsewhere on the board
RFID_SCK: U1.11 (AN11/RP13(1)/CN13/PMRD/RB13); also elsewhere on the board
UART_RX: U1.2 (RP22(1)/CN18/PMA1/RC6); also elsewhere on the board
UART_TX: U1.3 (RP23(1)/CN17/PMA0/RC7); also elsewhere on the board
WIN_BTN_DOWN: U1.43 (INT0/RP7(1)/CN23/PMD5/RB7); also elsewhere on the board
WIN_BTN_UP: U1.42 (PGEC3/ASCL1/RP6(1)/CN24/PMD6/RB6); also elsewhere on the board
WIN_CURRENT_ADC: TP_CURRENT1.1, U1.25 (AN6/RP16(1)/CN8/RC0); also elsewhere on the board
WIN_DIAGA: TP_WDIAG1.1, U1.27 (AN8/CVREF/RP18(1)/PMA2/CN10/RC2); also elsewhere on the board
WIN_DIAGB: U1.24 (AN5/C1IN+/RP3(1)/CN7/RB3); also elsewhere on the board
WIN_INA: U1.32 (TDO/PMA8/RA8); also elsewhere on the board
WIN_INB: U1.23 (AN4/C1IN-/RP2(1)/CN6/RB2); also elsewhere on the board
WIN_LIMIT: U1.41 (PGED3/ASDA1/RP5(1)/CN27/PMD7/RB5); also elsewhere on the board
WIN_PWM: TP_PWM1.1, U1.26 (AN7/RP17(1)/CN9/RC1); also elsewhere on the board

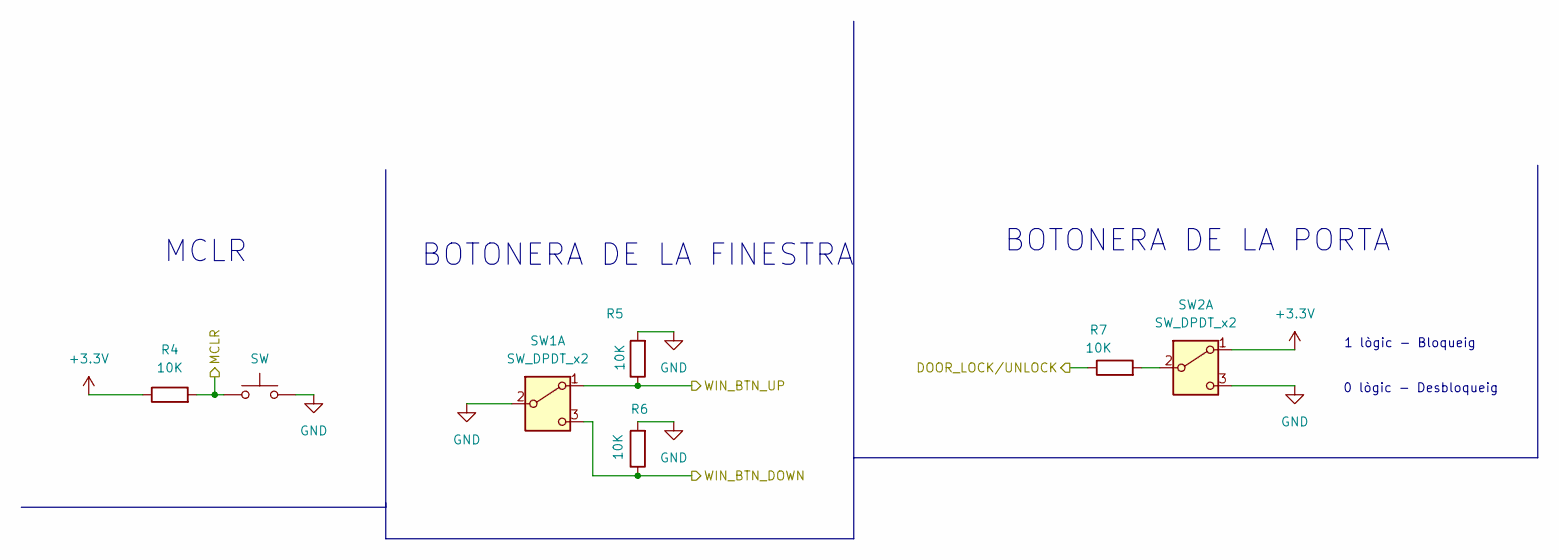
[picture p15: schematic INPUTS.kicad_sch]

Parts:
R4, R5, R6, R7: 10K; R_0805_2012Metric
SW1: SW_DPDT_x2; SW_DPDT_CK_JS202011JCQN
SW2: SW_DPDT_x2; SW_CK_JS202011CQN_DPDT_Straight
SW_UP1: SW; SW_SPST_TL3342

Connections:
+3.3V: R4.1, SW2.1 (A); also elsewhere on the board
DOOR_LOCK/UNLOCK: R7.1; also elsewhere on the board
GND: R5.2, R6.2, SW1.2 (B), SW2.3 (C), SW_UP1.2; also elsewhere on the board
MCLR: R4.2, SW_UP1.1; also elsewhere on the board
unnamed: R7.2, SW2.2 (B)
WIN_BTN_DOWN: R6.1, SW1.3 (C); also elsewhere on the board
WIN_BTN_UP: R5.1, SW1.1 (A); also elsewhere on the board

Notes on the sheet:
0 lògic - Desbloqueig
BOTONERA DE LA FINESTRA
1 lògic - Bloqueig
MCLR
BOTONERA DE LA PORTA

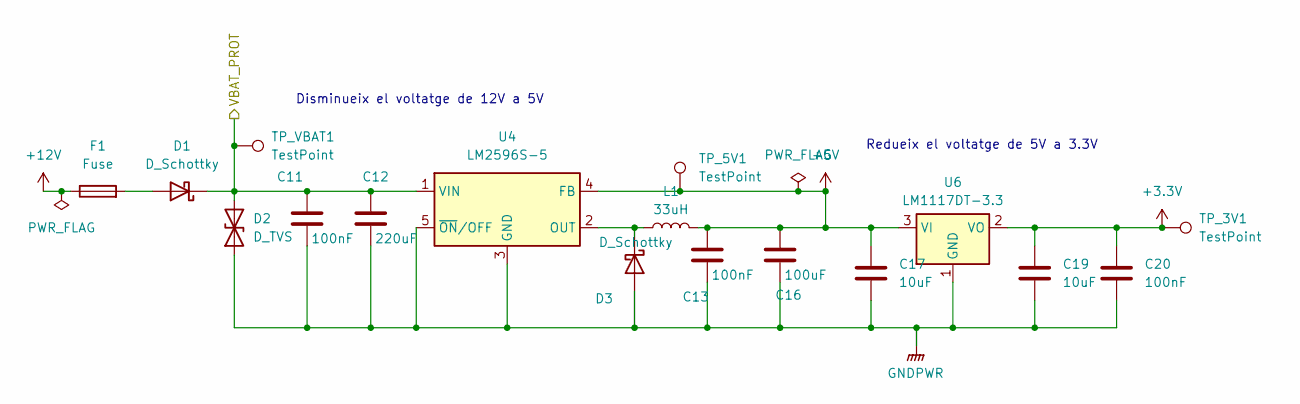
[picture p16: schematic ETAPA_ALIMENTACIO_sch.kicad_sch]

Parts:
C11, C13, C20: 100nF; C_0805_2012Metric
C12: 220uF; CP_Elec_8x10
C16: 100uF; CP_Elec_8x10
C17, C19: 10uF; C_1206_3216Metric
D1, D3: D_Schottky; D_SMB_Modified
D2: D_TVS; D_SMB_Modified
F1: Fuse; Fuse_1812_4532Metric
L1: 33uH; L_10.4x10.4_H4.8
TP_3V1, TP_5V1: TestPoint; TestPoint_Pad_D1.5mm
TP_VBAT1: TestPoint; TestPoint_Pad_D1.5mm
U4: LM2596S-5; TO-263-5_TabPin3
U6: LM1117DT-3.3; TO-252-3_TabPin2

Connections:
+3.3V: C19.1, C20.1, TP_3V1.1, U6.2 (VO); also elsewhere on the board
+5V: C13.1, C16.1, C17.1, L1.2, TP_5V1.1, U4.4 (FB), U6.3 (VI)
+12V: F1.1; also elsewhere on the board
GNDPWR: C11.2, C12.2, C13.2, C16.2, C17.2, C19.2, C20.2, D2.1 (A1), D3.2 (A), U4.3 (GND), U4.5 (~ON/OFF), U6.1 (GND); also elsewhere on the board
unnamed: D1.2 (A), F1.2
unnamed: D3.1 (K), L1.1, U4.2 (OUT)
VBAT_PROT: C11.1, C12.1, D1.1 (K), D2.2 (A2), TP_VBAT1.1, U4.1 (VIN); also elsewhere on the board

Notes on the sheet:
Disminueix el voltatge de 12V a 5V
Redueix el voltatge de 5V a 3.3V

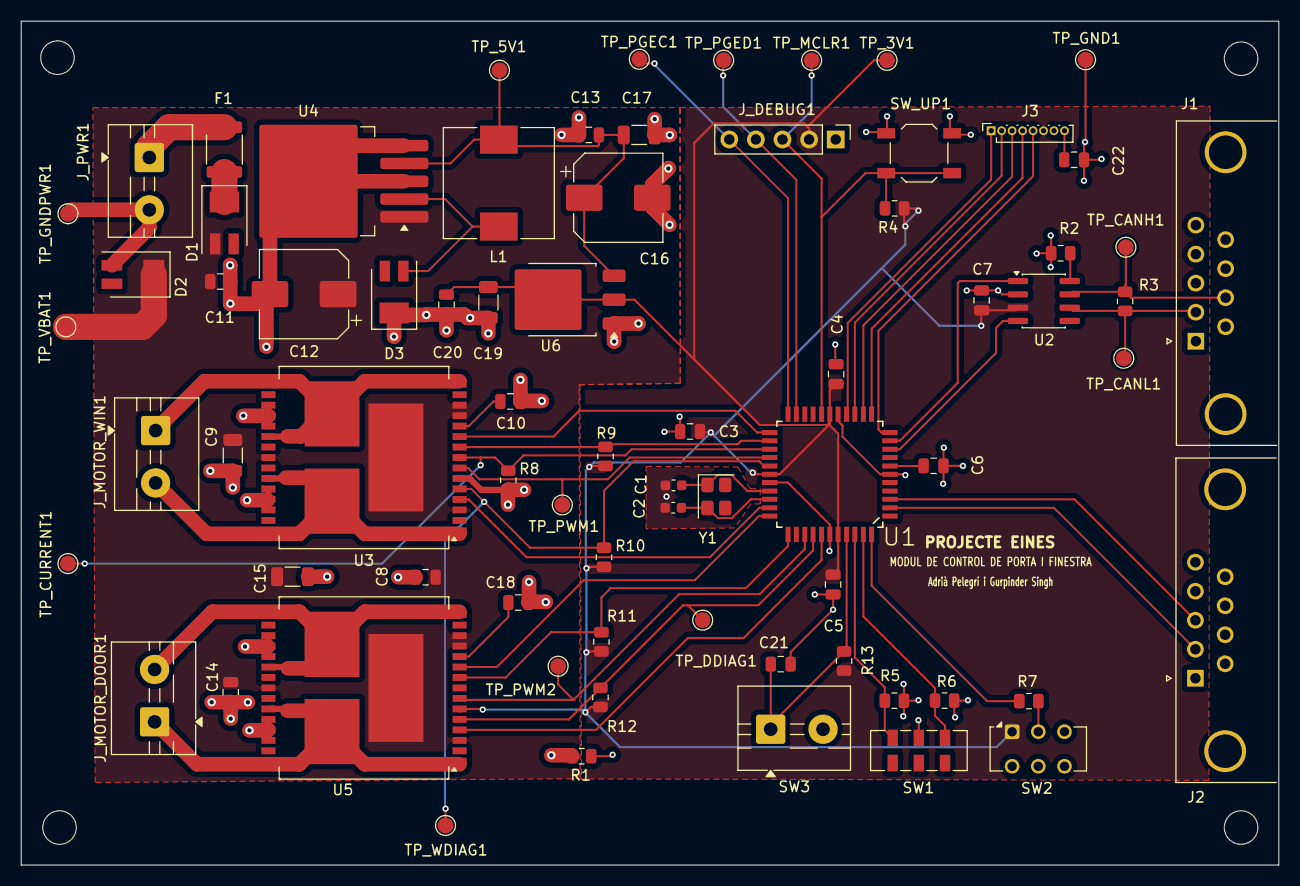
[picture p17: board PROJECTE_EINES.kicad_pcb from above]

Board: 2 copper layers, 120.1 x 80.6 mm, 73 parts (0 on the bottom side), 49 nets.

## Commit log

2026-03-12 CREACIÓ PROJECTE
    [PROJECTE_EINES.kicad_pcb, PROJECTE_EINES.kicad_sch]
2026-03-18 Nova versió diagrama de blocs i primera versió BOM
    [BOM_Projecte_Eines_Disseny.xlsx]
2026-03-19 CREACIÓ DE BLOCS DEL PROJECTE
    [BUS_CAN.kicad_sch, ETAPA_POTENCIA.kicad_sch, INPUTS.kicad_sch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]
2026-03-19 Actualització del sensor de corrent
    [ETAPA_POTENCIA.kicad_sch, PROJECTE_EINES.kicad_sch, SENSOR_CORRENT.kicad_sch]
2026-03-19 Versió amb el simbol del nou micro
    [MICROCONTROLADOR_DEBUG.kicad_sch, SENSOR_CORRENT.kicad_sch]
2026-03-19 Esquematic BUS creat + Diagrama blocs v.3.
    [BUS_CAN.kicad_sch, ETAPA_POTENCIA.kicad_sch, SENSOR_RFID.kicad_sch]
2026-03-19 aclaracions BUS CAN
    [BUS_CAN.kicad_sch, PROJECTE_EINES.kicad_sch]
2026-03-19 Update del micro
    [ETAPA_POTENCIA.kicad_sch]
2026-03-19 BUS CAN + USART +GND comuns
    [BUS_CAN.kicad_sch, ETAPA_POTENCIA.kicad_sch]
2026-03-25 Diagrama blocs versió 4 + BOM actualitzat + Bus CAN i USART + Lector RFID
    [BOM_Projecte_Eines_Disseny.xlsx, BUS_CAN.kicad_sch, PROJECTE_EINES.kicad_sch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]
2026-03-25 Footprints afegides a Comunicació, Sensor RFID i Sensor Corrent
    [BUS_CAN.kicad_sch, PROJECTE_EINES.kicad_sch, SENSOR_CORRENT.kicad_sch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]
2026-03-26 Actualizació final de les conexions del microcontrolador
    [MICROCONTROLADOR_DEBUG.kicad_sch, PROJECTE_EINES.kicad_sch]
2026-03-26 Actulització del driver del motor de finestra
    [MOTOR_FINESTRA.kicad_sch]
2026-03-26 Actulització etapa d'alimentació
    [ETAPA_POTENCIA.kicad_sch, PROJECTE_EINES.kicad_sch]
2026-03-26 Actualització README
    [ETAPA_POTENCIA.kicad_sch, PROJECTE_EINES.kicad_sch]
2026-03-26 Actualització Sheet Inputs
    [ETAPA_POTENCIA.kicad_sch, INPUTS.kicad_sch, PROJECTE_EINES.kicad_sch]
2026-03-26 Esquematic general conectat
    [MOTOR_FINESTRA.kicad_sch, PROJECTE_EINES.kicad_sch]
2026-03-26 ESQUEMATIC FINAL V.1
    [INPUTS.kicad_sch, MOTOR_FINESTRA.kicad_sch, PROJECTE_EINES.kicad_sch]
2026-03-26 Nova versió diagrama de blocs + BOM actualitzat + Nova versió KiCad
    [BOM_Projecte_Eines_Disseny.xlsx, BUS_CAN.kicad_sch, MOTOR_FINESTRA.kicad_sch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]
2026-03-26 Resistències pull-up arreglades als motors
    [MOTOR_FINESTRA.kicad_sch, MOTOR_PORTA.kicad_sch, PROJECTE_EINES.kicad_sch]
2026-03-26 Etiquetes de GND i VCC 3.3V canviades a simbols
    [BUS_CAN.kicad_sch, ETAPA_POTENCIA.kicad_sch, INPUTS.kicad_sch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]
2026-03-27 Eliminat .sch inecessari del projecte KiCad
    [untitled.kicad_sch]
2026-04-06 Correció etapa d'alimentació e Inputs
    [BUS_CAN.kicad_sch, ETAPA_POTENCIA.kicad_sch, INPUTS.kicad_sch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]
2026-04-07 Actualizació Footprints
    [INPUTS.kicad_sch, MICROCONTROLADOR_DEBUG.kicad_sch, MOTOR_FINESTRA.kicad_sch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]
2026-04-08 Update del nou Microcontrolador
    [MICROCONTROLADOR_DEBUG.kicad_sch]
2026-04-08 Versió final Esquematic
    [BUS_CAN.kicad_sch, ETAPA_ALIMENTACIO.kicad_sch, ETAPA_ALIMENTACIO_sch.kicad_sch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]
2026-04-09 Versió final de l'esquematic
    [ETAPA_POTENICA.kicad_sch, INPUTS.kicad_sch, MICROCONTROLADOR_DEBUG.kicad_sch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]
2026-04-09 1ra versióPCB
    [BUS_CAN.kicad_sch, ETAPA_POTENICA.kicad_sch, INPUTS.kicad_sch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]
2026-04-09 Versió 2.0 PCB
    [PROJECTE_EINES.kicad_pcb]
2026-04-09 Versió de placement PCB
    [ETAPA_POTENICA.kicad_sch, PROJECTE_EINES.kicad_pcb]
2026-04-15 Actulitació de components
    [BUS_CAN.kicad_sch, ETAPA_ALIMENTACIO_sch.kicad_sch, INPUTS.kicad_sch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]
2026-04-15 Bus CAN i USART
    [BUS_CAN.kicad_sch, ETAPA_ALIMENTACIO_sch.kicad_sch, ETAPA_POTENICA.kicad_sch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]
2026-04-15 Errors solucionats
    [BUS_CAN.kicad_sch, ETAPA_ALIMENTACIO_sch.kicad_sch, ETAPA_POTENICA.kicad_sch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]
2026-04-15 V3 layout
    [ETAPA_ALIMENTACIO_sch.kicad_sch, ETAPA_POTENICA.kicad_sch, INPUTS.kicad_sch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]
2026-04-15 Update pels dos
    [ETAPA_ALIMENTACIO_sch.kicad_sch, ETAPA_POTENICA.kicad_sch, INPUTS.kicad_sch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]
2026-04-15 V2 placement
    [BUS_CAN.kicad_sch, INPUTS.kicad_sch, PROJECTE_EINES.kicad_pcb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]
2026-04-15 REORDENACIÓ DEL MICRO
    [MICROCONTROLADOR_DEBUG.kicad_sch, PROJECTE_EINES.kicad_sch, SENSOR_CORRENT.kicad_sch]
2026-04-16 V1 Routing
    [BUS_CAN.kicad_sch, ETAPA_ALIMENTACIO_sch.kicad_sch, ETAPA_POTENICA.kicad_sch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]
2026-04-16 V2 Routing
    [PROJECTE_EINES.kicad_pcb]
2026-04-16 Update dels testpins
    [PROJECTE_EINES.kicad_pcb, PROJECTE_EINES.kicad_sch, test_points_sch.kicad_sch]
2026-04-16 Routing V3
    [MICROCONTROLADOR_DEBUG.kicad_sch, PROJECTE_EINES.kicad_pcb]
2026-04-29 Versió preliminar Routing Final
    [MICROCONTROLADOR_DEBUG.kicad_sch, PROJECTE_EINES.kicad_pcb]
2026-04-29 Actualització dels test points
    [BUS_CAN.kicad_sch, ETAPA_ALIMENTACIO_sch.kicad_sch, MICROCONTROLADOR_DEBUG.kicad_sch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]
2026-04-29 Versio final KiCad, BOM i Diagrama de Blocs
    [ETAPA_ALIMENTACIO_sch.kicad_sch, ETAPA_POTENICA.kicad_sch, PROJECTE_EINES.kicad_pcb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]
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2026-04-29 Afegida foodprint a R4 i actualitzada a la PCB
    [PROJECTE_EINES.kicad_pcb, SENSOR_CORRENT.kicad_sch]
2026-04-30 Versio final
    [ETAPA_ALIMENTACIO_sch.kicad_sch, ETAPA_POTENICA.kicad_sch, MICROCONTROLADOR_DEBUG.kicad_sch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]
2026-04-30 Versió Final projecte
    [BUS_CAN.kicad_sch, ETAPA_ALIMENTACIO_sch.kicad_sch, ETAPA_POTENICA.kicad_sch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]
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2026-04-30 Entrega final de projecte
    [PROJECTE_EINES.kicad_pcb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]
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
